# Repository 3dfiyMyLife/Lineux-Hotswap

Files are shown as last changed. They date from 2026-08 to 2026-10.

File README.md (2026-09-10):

# Lineux-Hotswap
### Diy Hotendchanger for fdm 3d printers
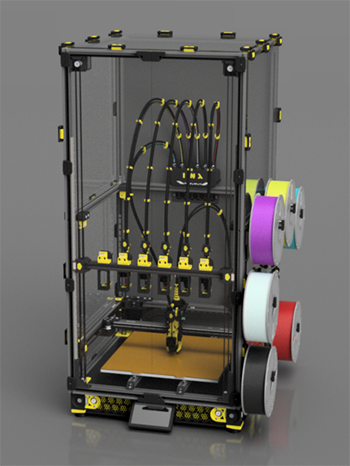
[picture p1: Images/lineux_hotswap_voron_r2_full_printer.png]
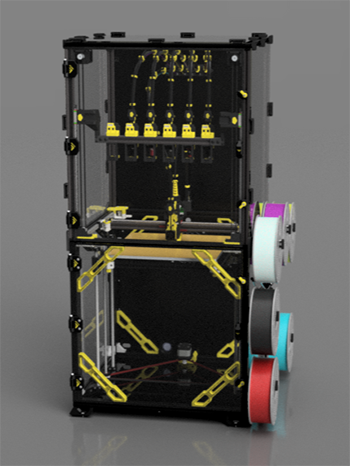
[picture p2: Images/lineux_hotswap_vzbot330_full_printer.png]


# Discord
Our Discord server can be found here:

Discord Banner 2 (https://discord.gg/Xwqbjj4VjH)
</a>

# Description
Lineux Hotswap consist of a suite of 3 parts:
1. Lineux - The hardware consisting of the Carriage, Toolhead and Dock
2. Btc - The macros handling the toolchange (Credit to @JackBeam for BTC)
3. Dockslide - Stowable dock to maximise print build

All 3 parts can be used with other systems. Example, Lineux can be used with other hotendchanger plugin. Other hotendchanger hardware can use Btc macros. Etc...

Lineux is designed as a front mounted Hotendchanger with Dockslide as our primary configuration.
If you intend to use a fixed dock configuration, pls do check or ask in discord if there are any mods or alternatives that may have already been released.

(Design, hardwares and configuration may change. Do check with us on discord)

# Is This Project for You?

This project is for makers and tinkerers who want to explore custom multi-tool 3D printing solutions.

If you’re simply looking for a plug-and-play machine, there are other great options available:

### Manufacture-ready Hotendchanger printers:
[Sovol M1D](https://www.sovol3d.com/pages/sovol-m1d-landing-page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)

### Other DIY hotendchanger projects:

[Cx Changer](https://github.com/cx330-TXY/CxChanger)

[Medusa HC](https://github.com/Irbis3D/MedusaHC)

[Yudx](https://github.com/dumplinglab/YUDX-tool-changer)

# All derivatives belong to their respective owners.<br/>
[Voron](https://github.com/vorondesign)<br/>
[Vzbot](https://github.com/VzBot3D)<br/>
[Voron CNC Carriage](https://github.com/Vitalii3D-xyz/VoronLightweightXCarriage)<br/>
[Voron Fysetc CNC Tap](https://github.com/FYSETC)<br/>

## Cost
Aside from costs at BOM, you will need these items. These are not included in the BOM
1. PSU. The power depends on the number of tools used. The hotend heater power also must be taken into account.
2. Probe. You will only need 1 probe.
3. PDB. All hotends, thermistor and hotend fans need their own ports respectively. If your mcu doesnt have enough ports for them, you need to use an additional board or an expansion board.

# BOM
BOM is [here](https://github.com/3dfiyMyLife/Lineux-Hotswap/tree/main/BOM)

# Current stage
Lineux Hotswap: Open Beta

BTC: Released

Dockslide: Released

# Instructions
Instructions/Guides are [here](https://github.com/3dfiyMyLife/Lineux-Hotswap/tree/main/Manuals)

# A huge thanks to the companies who have been supporting us
Blurolls https://blurolls3d.com/<br/>
LDO Motors https://ldomotors.com/<br/>
Polymaker https://polymaker.com/<br/>
E3D https://e3d-online.com/<br/>
RDBB rails https://a.aliexpress.com/_oB4RnLd<br/>
Fysect https://www.fysetc.com/<br/>
Trianglelab https://trianglelab.net/<br/>
Cartographer 3d https://cartographer3d.com/<br/>
JLCCNC https://jlccnc.com/<br/>
Biqu https://biqu.equipment/<br/>
Mellow 3d https://3dmellow.com/<br/>

# If you would like to support our project, you can do so on our Kofi Page
### [Ko-fi](https://ko-fi.com/lineux_toolchanger) ###

# Videos
https://github.com/user-attachments/assets/3e8e5f42-4552-4d9c-a9ab-b509341ac4d7

https://github.com/user-attachments/assets/85e045ab-b232-4179-8a6f-3297ebb0ea23

# Prints

Printed by 3dfiy My Life on vzbot330

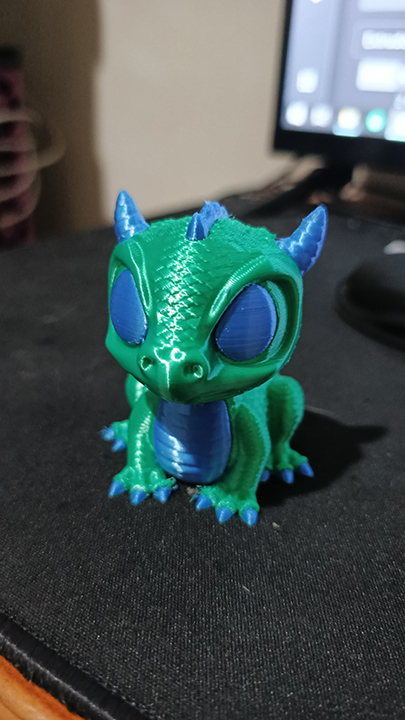
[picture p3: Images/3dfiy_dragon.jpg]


Printed by irrenhaus on voron trident r2

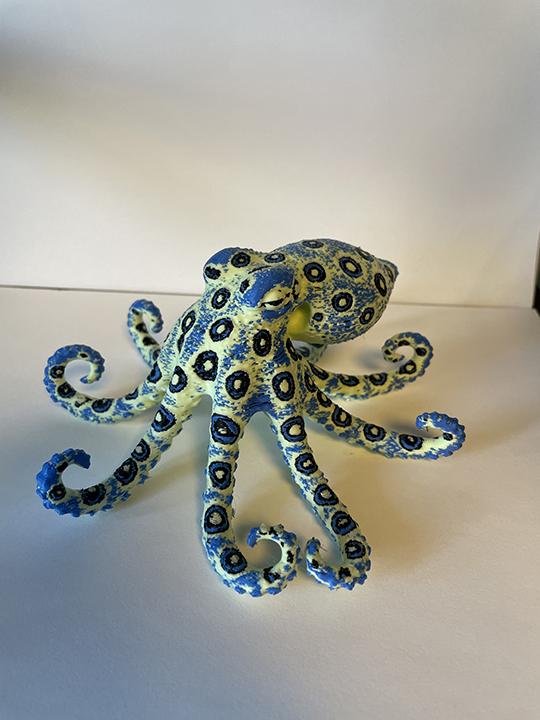
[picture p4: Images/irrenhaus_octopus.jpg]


# Printers
This project was developed on a Vzbot 330 and Voron 2.4 and Voron Trident. Other printers would need slight modifications. We could add support for other printers when there are others who had modded successfully, or when
we are able to get a hold of other printers to mod.

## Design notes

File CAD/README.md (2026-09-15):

# Overview

## Lineux Hotswap (Open Beta Release)
All cads released are based on a Voron 2.4 and Vzbot. You might need to adapt the dock and carriage to yr own printers. You can also check usermods section for any other printers cad/stl that may have been contributed by the community if they are not available here. Pls also do check in discord for any mods/contributions by the community.

Designs, mechanism and bom do get updated as we progress. Do take note. (It's a good practice to ask before committing to the build as design and hardwares may change)

# Printed Parts
Ensure the printed parts are printed without any warping to ensure proper and perfectly aligned components during installation.

It is recommended to do a test print on a small part for fitting, material shrinkage and tolerance measurement before commiting to the full printed parts.

Recommended slicer settings are as follows (Props to Voron team):
```
Layer height: 0.2mm
Extrusion width: 0.4mm
Infill pecentage: 40%
Infill type: Adaptive Cubic, grid, gyroid, honeycomb, triangle, or cubic
Wall count: 4
Solid top/bottom layers: 5
```

# Carriage
Refer to the printer carriage available or check under usermods section. Pls do check in discord as well. All carriages are designed to be front facing and utilising Dockslide.
If you are running Lineux Hotswap on a Voron 2.4 r2, you will need to use the Z chain transpose as well eg, https://www.printables.com/model/279739-voron-can-bus-z-chain-move
There are a few versions which you can search and use.

# Toolhead
Currently, we offer a few hotends compability. Do check on discord for other hotends compability which may have been made by the community.<br/>
Mellow V6 CHP<br/>
Triangle CHC pro<br/>
TZ V6 3.0<br/>
E3D Revo Voron<br/>
Phaetus Rapido<br/>

# Docks
Docks are optimized to be used with a dockslide. Do check with our discord for other types which may have been contributed by the community.

# Dockslide
Dockslide is a moving dock system to recover back any build volume loss encountered when having a fixed dock on the existing printer in which the frame wasn't extended in X or Y.

# Requirement
1. Carriage
2. Tools (Quantity depends on how many you require or may fit on yr printer. Minimum of 2 toolheads recomended)
3. Docks (1 dock per toolhead required)
4. Dockslide (You will need a fixed dock mount if you are not using dockslide)
5. Tubby / Intai (Required for tool nozzle offset calibration)

Join our [Discord](https://discord.gg/Xwqbjj4VjH) for any questions u may have. Let's go...

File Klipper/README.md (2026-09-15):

# Overview
Bikin Toolchanger (BTC) is using pure macros. It uses snippets of codes from the [Magswitch](https://github.com/jera-sea/MagSwitch-Toolchanger) project and the
[Klicky Probe](https://github.com/jlas1/Klicky-Probe).

# Nozzle Offset Calibration Tool
You can use Tubby, Intai, Nudge, Mellow Zero Precision, or any camera calibration or manual calibration. 

# Macro Status
Fully tested and working. Released.

# Files
1. btc.cfg <- Main file, required
2. btc_carriage.cfg	<- Carriage file, required
3. btc_variables.cfg <- Variables, required
4. tool_x.cfg <- Individual tool settings, required
5. btc_leds.cfg <- Leds macros, required
6. dockslide.cfg <- Required if using dockslide
7. bashed_macros.cfg <- For stress testing of hotendchanger, required after set up
8. btc_tubby.cfg <- Macros for tubby tool, required during nozzle offset calibration set up
9. btc_tubby_z.cfg <- Macros for Z calibration only if using camera for X and Y nozzle offset
10. btc_extras.cfg <- Sample macros to use in start/end print and homing override
11. btc_spoolman.cfg <- Required if using Spoolman

# Video guide

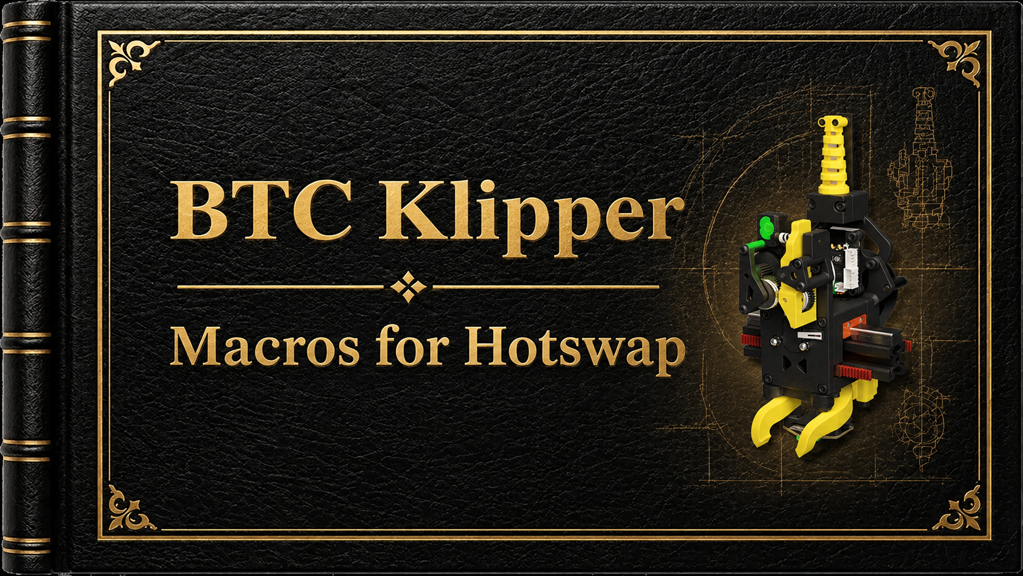
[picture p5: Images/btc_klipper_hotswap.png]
IMAGE ALT TEXT HERE (https://youtu.be/aBgHKiLgzWA?si=D5ylQy5s1Cmdv41K)


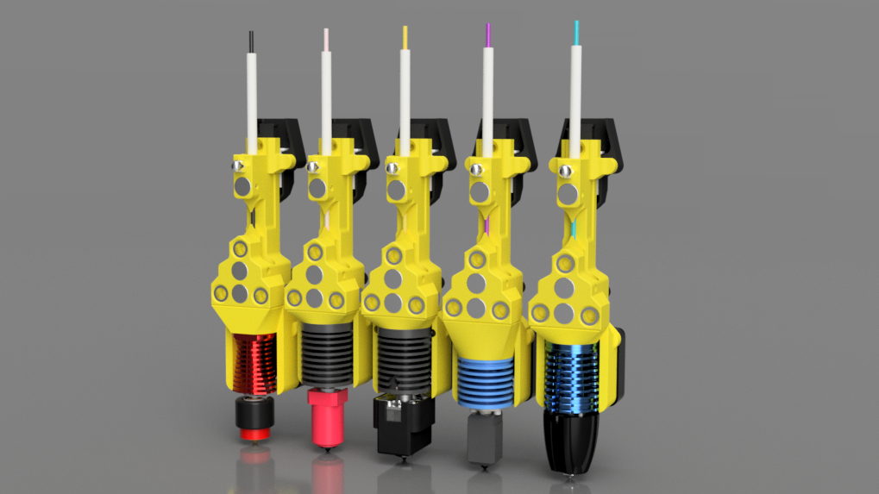
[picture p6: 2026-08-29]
Images/lineux_hotswap_tool_rear.png

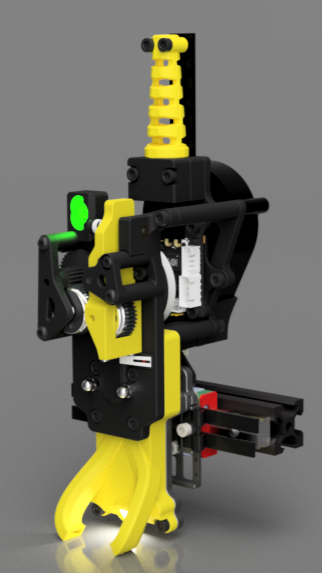
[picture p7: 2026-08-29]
Images/lineux_hotswap_cnc_tap.png

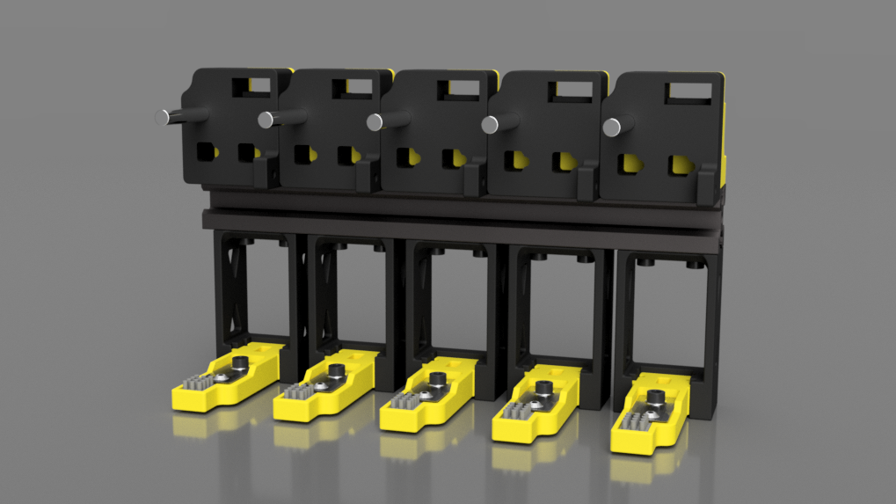
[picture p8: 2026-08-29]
Images/lineux_hotswap_docks_rear.png

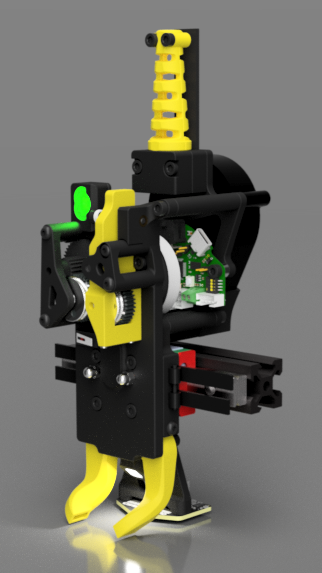
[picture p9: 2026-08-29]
Images/lineux_hotswap_voron.png

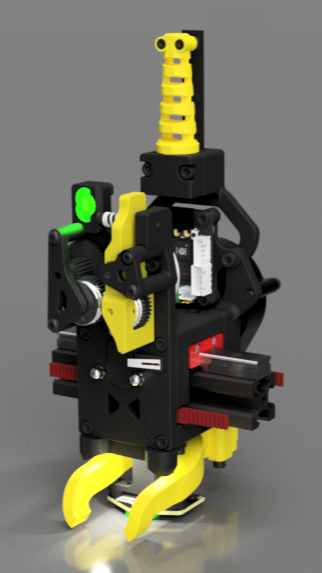
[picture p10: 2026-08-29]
Images/lineux_hotswap_vzbot.png

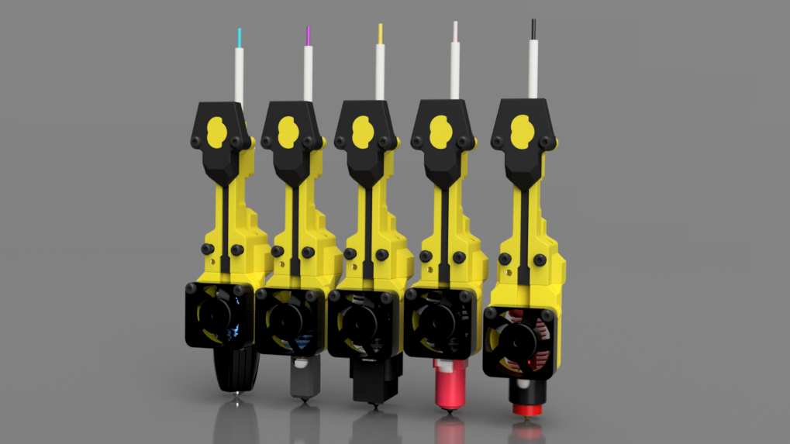
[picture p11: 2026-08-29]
Images/lineux_hotswap_tool_front.png

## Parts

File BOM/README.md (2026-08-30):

Bom are subjected to change based on testing, updates and hardwares availability.

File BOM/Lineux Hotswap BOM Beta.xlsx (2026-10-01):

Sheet: Voron
Lineux Hotswap Bill Of Material (Alpha)
Bom subjected to changes based on feedbacks and hardware availability.
Bom doesn't include probe and their respective hardwares.
Bom is for Ebb36 Toolboard. Other toolboard may need different hardwares.
Lineux Hotswap Voron Carriage | Quantity | Description | Source link | Remarks
m3x5x4 brass insert | 26
m3 hex nut | 1
m3 x 6mm bhcs | 3
m3 x 6mm shcs | 1
m3 x 8mm set screw | 3
m3 x 8mm shcs | 5
m3 x 15mm shcs | 4
m3 x 20mm shcs | 2
m3 x 25mm bhcs | 4
m3 x 30mm bhcs | 4
m3 x 30mm shcs | 1
m3 x 45mm shcs | 2
m3 cap nut din1587 | 3 |  | link (https://www.aliexpress.com/item/1005011936970787.html)
m3 x 20mm dowel pin | 2
m3 x 30mm dowel pin | 2
M5 OD7 3mm SS Bushing | 1 | 5x7x3 | link (https://www.aliexpress.com/item/1005008882769763.html)
mr63zz bearing | 2 |  |  | U need 2 extra. Not from HGX Lite kit
8 x 5mm n52 magnet | 3
microswitch | 1
ws2812 Addressable Led | 2
Nema 14 Stepper motor | 1
HGX Lite Gears | 1 | Gear Kit | link (https://www.aliexpress.com/item/1005008784674964.html) | Take note its not HGX Lite V2
Toolboard | 1 |  |  | Ebb36, H36, SHT36, Tool Lite, etc
5015 Radial Fan | 1
Lineux Hotswap Voron Dock | Quantity | Description | Source link | Remarks
m3x5x4 brass insert | 5
m3 hex nut | 1
m3 washer | 2
m3 x 6mm shcs | 3
m3 x 8mm shcs | 3
m3 x 10mm shcs | 4
m3 od5 35mm threaded dowel pin | 1 | 5x35xM3 | link (https://www.aliexpress.com/item/1005008733851932.html)
6 x 3mm n52 magnet | 1
Silicon Brush | 1 |  | link (https://www.aliexpress.com/item/1005012043811349.html) | Can be cut into 2 or 3 per piece
AA battery terminal | 1 |  | link (https://www.aliexpress.com/item/1005003438264831.html?curPageLogUid=9sgHbNrWVcU1) | Take note of dimension

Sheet: Voron Cnc Tap
Lineux Hotswap Bill Of Material (Alpha)
Bom subjected to changes based on feedbacks and hardware availability.
Bom doesn't include probe and their respective hardwares.
Bom is for Ebb36 Toolboard. Other toolboard may need different hardwares.
Lineux Hotswap Voron Carriage | Quantity | Description | Source link | Remarks
m3x5x4 brass insert | 26
m3 hex nut | 1
m3 x 6mm shcs | 6
m3 x 8mm set screw | 3
m3 x 8mm shcs | 7
m3 x 12mm shcs | 2
m3 x 20mm shcs | 2
m3 x 25mm bhcs | 4
m3 x 30mm bhcs | 4
m3 x 30mm shcs | 1
m3 x 45mm shcs | 2
m3 x 20mm dowel pin | 2
m3 x 30mm dowel pin | 2
m3 cap nut din1587 | 3 |  | link (https://www.aliexpress.com/item/1005011936970787.html)
M5 OD7 3mm SS Bushing | 1 | 5x7x3 | link (https://www.aliexpress.com/item/1005008882769763.html)
mr63zz bearing | 2 |  |  | U need 2 extra. Not from HGX Lite kit
8 x 5mm n52 magnet | 3
microswitch | 1
ws2812 Addressable Led | 2
Nema 14 Stepper motor | 1
HGX Lite Gears | 1 | Gear Kit | link (https://www.aliexpress.com/item/1005008784674964.html) | Take note its not HGX Lite V2
Toolboard | 1 |  |  | Ebb36, H36, SHT36, Tool Lite, etc
5015 Radial Fan | 1
Lineux Hotswap Voron CNC Tap Dock | Quantity | Description | Source link | Remarks
m3x5x4 brass insert | 5
m3 hex nut | 1
m3 washer | 2
m3 x 6mm shcs | 3
m3 x 8mm shcs | 3
m3 x 10mm shcs | 4
m3 od5 35mm threaded dowel pin | 1 | 5x35xM3 | link (https://www.aliexpress.com/item/1005008733851932.html)
6 x 3mm n52 magnet | 1
Silicon Brush | 1 |  | link (https://www.aliexpress.com/item/1005012043811349.html) | Can be cut into 2 or 3 per piece
AA battery terminal | 1 |  | link (https://www.aliexpress.com/item/1005003438264831.html?curPageLogUid=9sgHbNrWVcU1) | Take note of dimension

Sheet: Vzbot
Lineux Hotswap Bill Of Material (Alpha)
Bom subjected to changes based on feedbacks and hardware availability.
Bom doesn't include probe and their respective hardwares.
Bom is for Ebb36 Toolboard. Other toolboard may need different hardwares.
Lineux Hotswap Vzbot Carriage | Quantity | Description | Source link | Remarks
m3x5x4 brass insert | 36
m3 hex nut | 3
m3 x 8mm set screw | 3
m3 x 6mm shcs | 14
m3 x 8mm shcs | 7
m3 x 10mm shcs | 2
m3 x 16mm shcs | 2
m3 x 20mm shcs | 2
m3 x 25mm bhcs | 2
m3 x 30mm bhcs | 4
m3 x 30mm shcs | 1
m3 x 45mm shcs | 2
m3 cap nut din1587 | 3 |  | link (https://www.aliexpress.com/item/1005011936970787.html)
M5 OD7 3mm SS Bushing | 1 | 5x7x3 | link (https://www.aliexpress.com/item/1005008882769763.html)
m3 x 20mm dowel pin | 4
m3 x 30mm dowel pin | 2
mr63zz bearing | 2 |  |  | U need 2 extra. Not from HGX Lite kit
8 x 5mm n52 magnet | 3
microswitch | 1
ws2812 Addressable Led | 3
Nema 14 Stepper motor | 1
HGX Gears | 1 | Gear Kit | link (https://www.aliexpress.com/item/1005008784674964.html) | Take note its not HGX Lite V2
Toolboard | 1 |  |  | Ebb36, H36, SHT36 etc
5015 Radial Fan | 1
Lineux Hotswap Vzbot Dock | Quantity | Description | Source link | Remarks
m3x5x4 brass insert | 5
m3 hex nut | 1
m3 washer | 2
m3 x 6mm shcs | 3
m3 x 8mm shcs | 5
m3 x 10mm shcs | 2
m3 od5 35mm threaded dowel pin | 1 | 5x35xM3 | link (https://www.aliexpress.com/item/1005008733851932.html)
6 x 3mm n52 magnet | 1
Silicon Brush | 1 |  | link (https://www.aliexpress.com/item/1005012043811349.html) | Can be cut into 2 or 3 per piece
AA battery terminal | 1 |  | link (https://www.aliexpress.com/item/1005003438264831.html?curPageLogUid=9sgHbNrWVcU1) | Take note of dimension

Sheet: Tool
Lineux Hotswap Bill Of Material (Alpha)
Bom subjected to changes based on feedbacks and hardware availability.
Bom is based on V6 ChP. Other hotends may require different hardwares.
Lineux Hotswap Toolhead | Quantity | Description | Source link | Remarks
m2.5 x 6mm shcs | 4 | For V6 CHP |  | Heatsink Mounting Screw
m3x5x4 brass insert | 9
m3 x 6mm fhcs | 1
m3 x 8mm set screw | 1
m3 x 8mm shcs | 2
m3 x 10mm bhcs | 2
m3 x 12mm bhcs | 2
m3 x 15mm bhcs | 2 |  |  | m3 x 16mm also possible
m3 cap nut din1587 | 1 |  | link (https://www.aliexpress.com/item/1005011936970787.html)
M5 OD7 3mm SS Bushing | 3 | 5x7x3 | link (https://www.aliexpress.com/item/1005008882769763.html)
6 x 3mm n52 magnet | 1
8 x 5mm n52 magnet | 3
3010 Axial Fan | 1 | between 9-12mm width |  | Length depends on printer size
Industrial ziptie (between 9-10mm width recommended) | 1 | For umbilical |  | Length depends on yr build.
jst xh 4pin female housing | 1 | Can use Molex 2x3p as an alternative | link (https://www.aliexpress.com/item/1005007287524489.html?curPageLogUid=jkflrg33MYGo) | Take note of the type
jst xh 4pin male | 1
molex 1x2pin male | 1 |  | link (https://www.aliexpress.com/item/1005006994933599.html?curPageLogUid=Kcjoww0hTpt0) | Take note of the clip position
molex 1x2pin female | 1 |  | link (https://www.aliexpress.com/item/1005006994933599.html?curPageLogUid=Kcjoww0hTpt0)
Ptfe Tube ID2 OD4 | 1 | 40mm |  | Length depends on hotends.
Hotend |  |  |  | Depends on your choice

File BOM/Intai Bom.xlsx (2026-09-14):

Intai- Camera Based Nozzle Offset Calibration Tool
Bom subjected to changes based on feedbacks and hardware availability.
All links are non affiliated. Links are provided as a reference to check the hardware dimensions, visual, etc.
Fixed Base (Magnet Version) | Quantity | Description | Link
m3x5x4 brass insert | 4
m3 x 6mm bhcs | 1
m3 x 8mm shcs | 2
m3 x 12mm bhcs | 3
m3 x 15mm bhcs | 1
m3 x OD4 16mm threaded dowel pin | 1 |  | link (https://www.aliexpress.com/item/1005005150593994.html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)
6 x 3mm magnet | 2 | n35 or lower
OV9726 Camera module | 1 |  | link (https://www.aliexpress.com/item/1005004029465825.html)
5v 3mm white led diode | 6 |  | link (https://www.aliexpress.com/item/1005004771200688.html)
jst xh2.54 connector 2pin female | 1 | Refer to cad if unsure which is female
Ring Terminal (RNB 1.25-3) | 1 | optional
Floating Base (Magnet Version) | Quantity | Description
m3x5x4 brass insert | 4
m3 x 6mm bhcs | 1
m3 x 12mm bhcs | 3
m3 x 15mm bhcs | 1
m3 x OD4 16mm threaded dowel pin | 1 |  | link (https://www.aliexpress.com/item/1005005150593994.html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)
6 x 3mm magnet | 2 | n35 or lower
6 x 3mm magnet | 4 | n52
OV9726 Camera module | 1 |  | link (https://www.aliexpress.com/item/1005004029465825.html)
5v 3mm white led diode | 6 |  | link (https://www.aliexpress.com/item/1005004771200688.html)
jst xh2.54 connector 2pin female | 1 | Refer to cad if unsure which is female
Ring Terminal (RNB 1.25-3) | 1 | optional
Floating Base (Switch Version) | Quantity | Description
m3x5x4 brass insert | 4
m3 x 12mm bhcs | 2
m3 x 15mm bhcs | 2
m3 x 10mm dowel pin | 1
m3 x OD4 16mm threaded dowel pin | 1 |  | link (https://www.aliexpress.com/item/1005005150593994.html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)
6 x 3mm magnet | 4 | n52
microswitch | 1
OV9726 Camera module | 1 |  | link (https://www.aliexpress.com/item/1005004029465825.html)
5v 3mm white led diode | 6 |  | link (https://www.aliexpress.com/item/1005004771200688.html)
jst xh2.54 connector 2pin female | 1 | Refer to cad if unsure which is female

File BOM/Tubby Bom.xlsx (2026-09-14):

Tubby - Nozzle Offset Calibration Tool
6x3mm Floating Base | Quantity | Description
m3 x 6mm shcs | 1
m3 x 16mm bhcs | 2
m3 brass insert | 2
m3 x 8mm dowel | 1 | Solder a wire to one end of the dowel
12mm steel ball bearing | 1
6 x 3mm n35 magnet | 6 | n35 or lower
JST XH 2.1 Female | 1
8x5mm Floating Base | Quantity | Description
m3 x 6mm shcs | 1
m3 x 16mm bhcs | 2
m3 brass insert | 2
m3 x 8mm dowel | 1 | Solder a wire to one end of the dowel
12mm steel ball bearing | 1
6 x 3mm n35 magnet | 3 | n35 or lower
8 x 5mm n35 magnet | 3 | n35 or lower
JST XH 2.1 Female | 1
10x5mm Floating Base | Quantity | Description
m3 x 6mm shcs | 1
m3 x 16mm bhcs | 2
m3 brass insert | 2
m3 x 8mm dowel | 1 | Solder a wire to one end of the dowel
12mm steel ball bearing | 1
6 x 3mm n35 magnet | 3 | n35 or lower
10 x 5mm n35 magnet | 3 | n35 or lower
JST XH 2.1 Female | 1
Fixed Base | Quantity | Description
m3 x 15mm shcs | 1
m3 x 16mm bhcs | 2
m3 x 25mm shcs | 2
m3 brass insert | 2
m3 x 8mm dowel | 1 | Solder a wire to one end of the dowel
12mm steel ball bearing | 1
6 x 3mm n35 magnet | 3 | n35 or lower
JST XH 2.1 Female | 1

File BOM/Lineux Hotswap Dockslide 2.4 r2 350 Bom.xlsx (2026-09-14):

Lineux Hotswap Dockslide 2.4 r2 350 Bill Of Material
Bom subjected to changes based on feedbacks and hardware availability.
Bom does not include panel clip/latch, door hinge and their respective hardwares.
Item | Quantity | Description | Source link | Remarks
2020 T-slot extrusion 1000mm | 2 | Tophat height is 470mm |  | Use the calculator below to get the required front extrusion length and rail length. Tophat height may be affected by bed size and umbilical length.
2020 T-slot extrusion 490mm | 2
2020 T-slot extrusion 470mm | 4
2020 T-slot extrusion 400mm | 1
MGN9C + Rail 650mm | 2
GT2 20T Pulley 9mm Belt ID5 | 2 |  |  | 10mm belt is fine too.
GT2 20T Toothed Idler 9mm Belt ID5 | 2 |  |  | 10mm belt idler is fine too.
Gates Belt 9mm 1.9metres | 2
Nema 17 Stepper | 2 | LDO-42STH40-1684AC |  | Recommended Motor
Micro switch | 2
m3 heat insert | 2 |  |  | m3xod5x4
m3 x 8mm bhcs | 8
m3 x 8mm shcs | 34
m3 x 20mm bhcs | 2
m3 x 25mm shcs | 8
m3 x 40mm shcs | 2
m5 x 8mm bhcs | 2
m5 x 10mm bhcs | 18
m5 x 20mm bhcs | 2
2020 hidden corner bracket | 16 |  |  | If not using blind joints
2020 parallel joint | 4
2020 straight line joint | 2
Panels
Top 504 x 484mm | 1 | Transparent |  | Size is based on Voron 2.4 r2 350
Sides 504 x 344mm | 2 | Transparent
Back 484 x 344mm | 1 | Opaque
Door 241.5 x 973.5mm | 2 | Transparent
Dockslide Required Length Calculator
Description |  | Enter Length | Required Length | Remarks
Step 1. To calculate the required dockslide vertical extrusion length, enter yr printer front vertical extrusion length |  | 530 | 1000 | Length may be affected by bed size and umbilical length.
Step 2. To calculate the required rail length, enter yr dockslide required vertical extrusion length |  | 1000 | 650
Step 3. To calculate dock extrusion bar length, enter yr printer horizontal extrusion length |  | 470 | 400
Step 4. To calculate the maximum number of tools you can install, enter dock extrusion bar length |  | 400 | 10 | Round down number

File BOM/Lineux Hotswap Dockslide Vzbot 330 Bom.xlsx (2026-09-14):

Dockslide Vzbot 330 Bill Of Material
Bom subjected to changes based on feedbacks and hardware availability.
Bom does not include panel clip/latch, door hinge and their respective hardwares.
Item | Quantity | Description | Source link | Remarks
2020 T-slot extrusion 550mm | 4 | Tophat height is 565mm
2020 T-slot extrusion 530mm | 2
2020 T-slot extrusion 460mm | 2
2020 T-slot extrusion 360mm | 1
MGN9H + Rail 350mm | 2
Hardware | Quantity | Description | Source link | Remarks
GT2 20T Pulley 9mm Belt ID5 | 2 |  |  | 10mm belt is fine too.
GT2 20T Toothed Idler 9mm Belt ID5 | 2 |  |  | 10mm belt idler is fine too.
Gates Belt 9mm 1.1 meter | 2
Nema 17 Stepper | 2 | LDO-42STH40-1684AC |  | Recommended Motor
Micro switch | 2
m3 heat insert | 2 |  |  | m3xod5x4
m3 x 8mm bhcs | 8
m3 x 8mm shcs | 16
m3 x 20mm bhcs | 2
m3 x 25mm shcs | 8
m3 x 40mm shcs | 2
m5 x 8mm bhcs | 8 |  |  | For corner bracket
m5 x 10mm bhcs | 34
m5 x 20mm bhcs | 2
m5 t-nut | 8 |  |  | For corner bracket
2020 corner bracket | 4 |  |  | Optional For stiffness
2020 hidden corner bracket | 4 |  |  | Optional For stiffness
Panels
Top 503.5 x 473.5mm | 1 | Transparent
Sides 556.5 x 470.5mm | 2 | Transparent
Back 555.0 x 504.5mm | 1 | Opaque
Door 564.5 x 516mm | 1 | Transparent

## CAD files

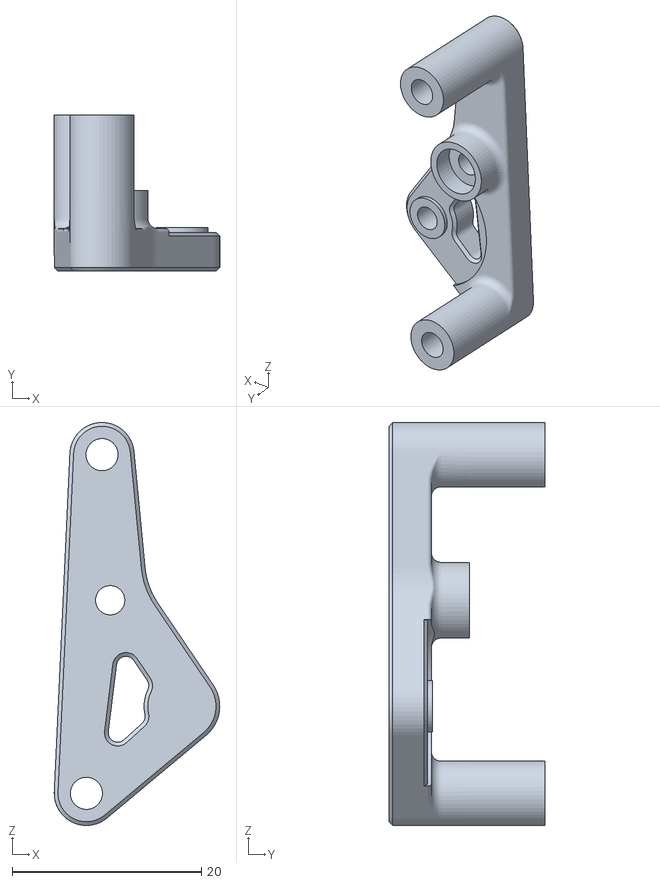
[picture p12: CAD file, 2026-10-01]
STLs/Carriage/Voron Cnc Tap/Carriage/gear_plate.stl
17.5 x 16.5 x 42.6

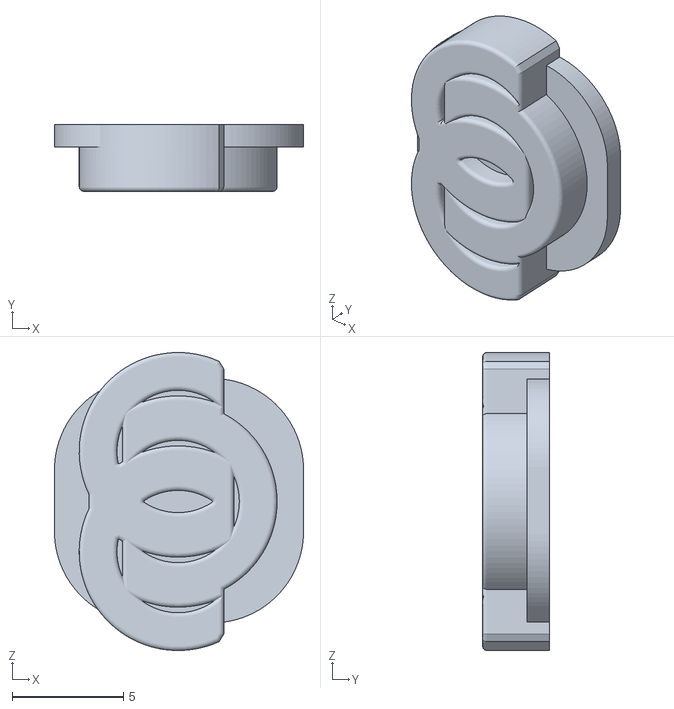
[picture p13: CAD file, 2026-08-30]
STLs/Carriage/Voron Cnc Tap/Led/diffuser.stl
11.2 x 3.00 x 13.4

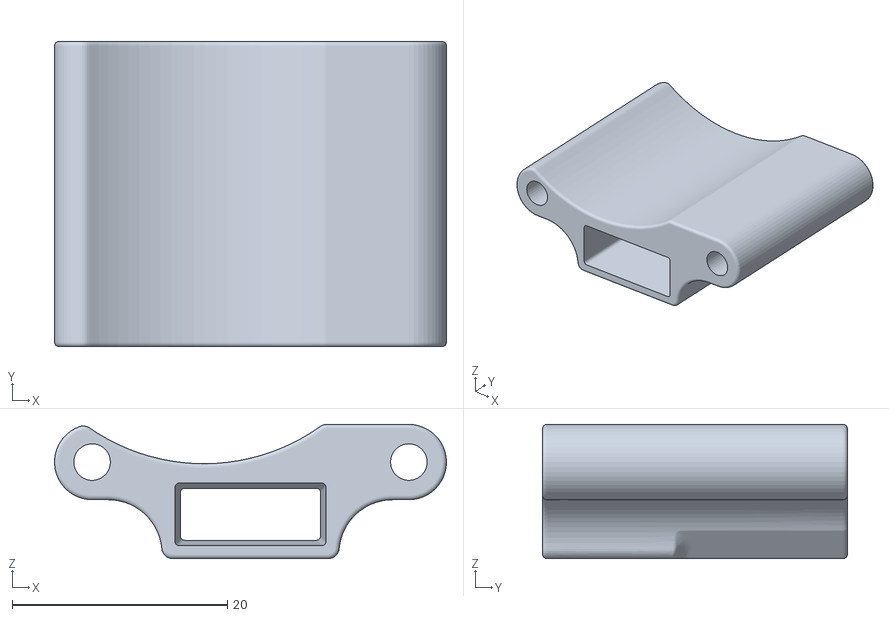
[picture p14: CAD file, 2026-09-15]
STLs/Carriage/Voron Cnc Tap/Part Cooling/duct_extension.stl
36.4 x 28.4 x 12.5

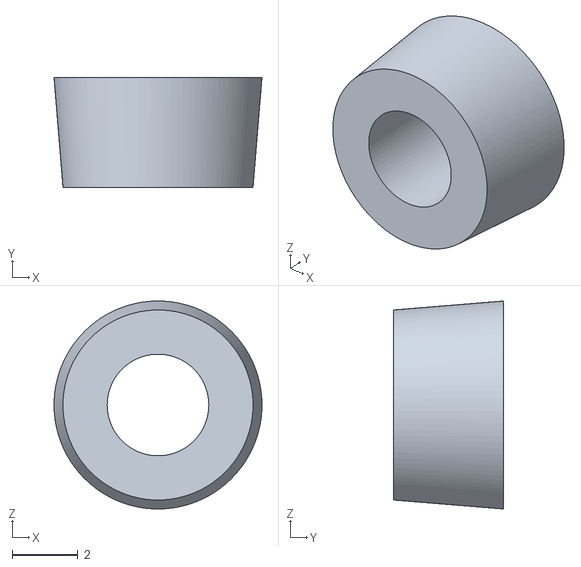
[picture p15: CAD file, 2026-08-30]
STLs/Carriage/Voron Cnc Tap/Toolboard/ebb36_spacer_x2.stl
6.35 x 3.36 x 6.35

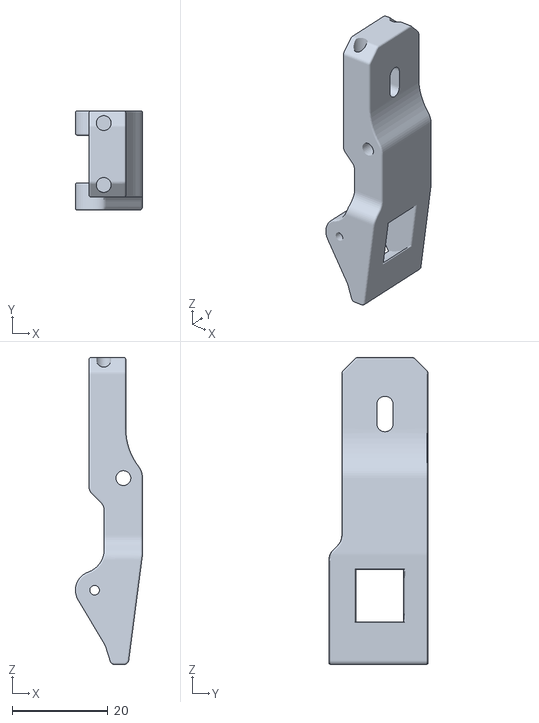
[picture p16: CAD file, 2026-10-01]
STLs/Carriage/Voron/Carriage/[a]_latch.stl
14.0 x 20.7 x 64.0

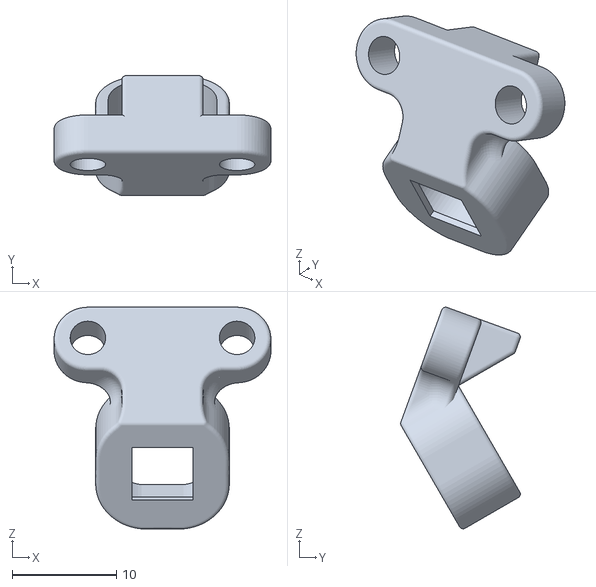
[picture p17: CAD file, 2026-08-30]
STLs/Carriage/Voron/Led/led_mount.stl
20.8 x 11.5 x 21.2

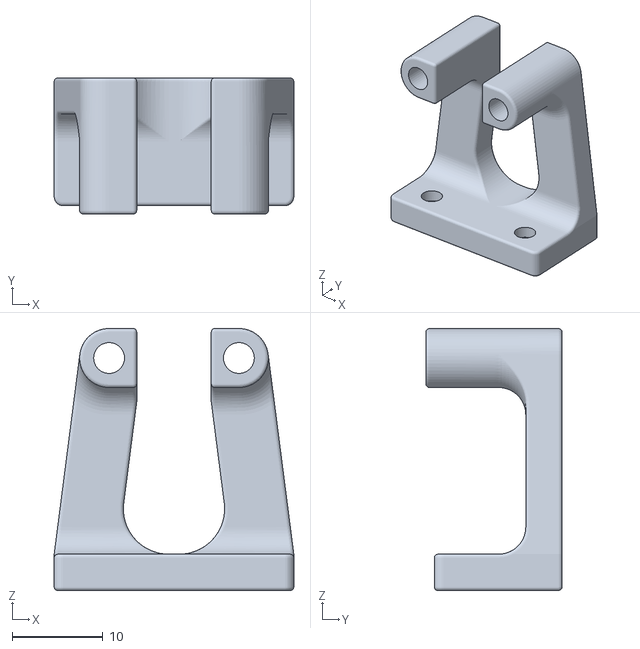
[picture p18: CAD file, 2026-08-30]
STLs/Carriage/Voron/Probe/klicky_mount.stl
26.4 x 15.0 x 28.9

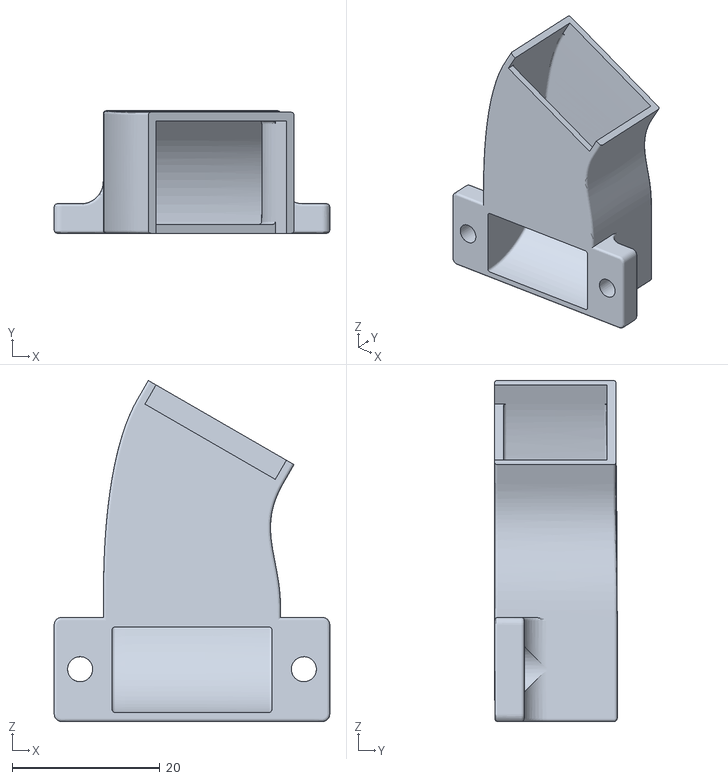
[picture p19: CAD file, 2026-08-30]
STLs/Carriage/Vzbot330/Part Cooling/[a]_5015_adapter.stl
37.3 x 16.6 x 46.2

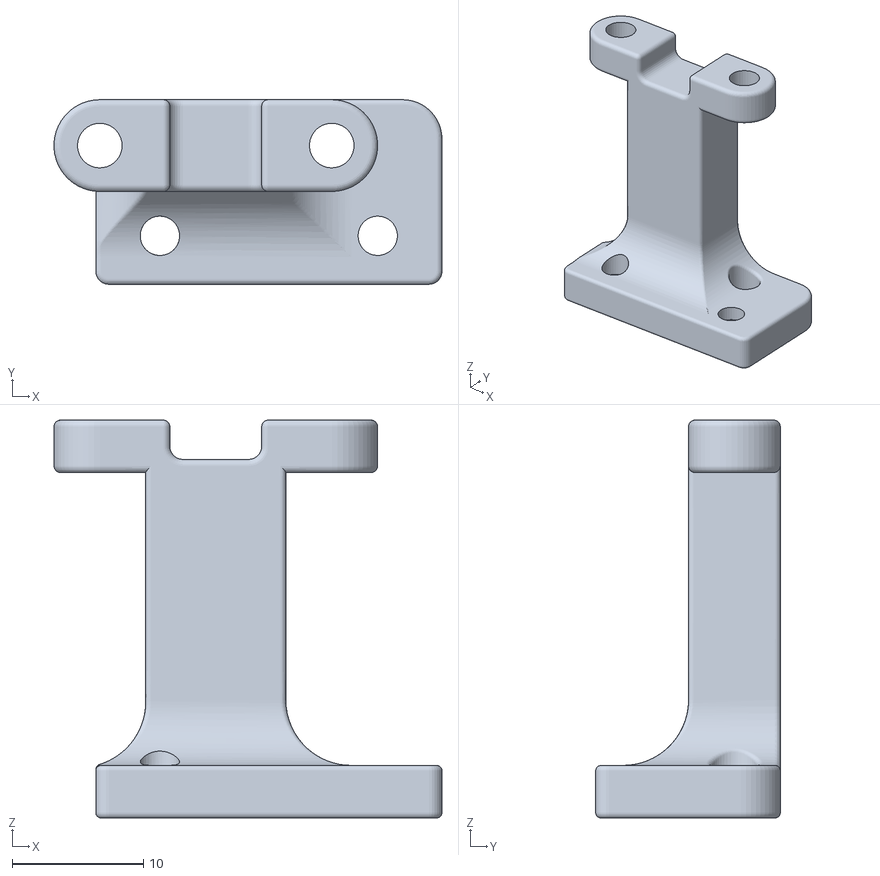
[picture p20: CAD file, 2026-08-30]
STLs/Carriage/Vzbot330/Probe/klicky_mount.stl
29.6 x 14.1 x 30.3

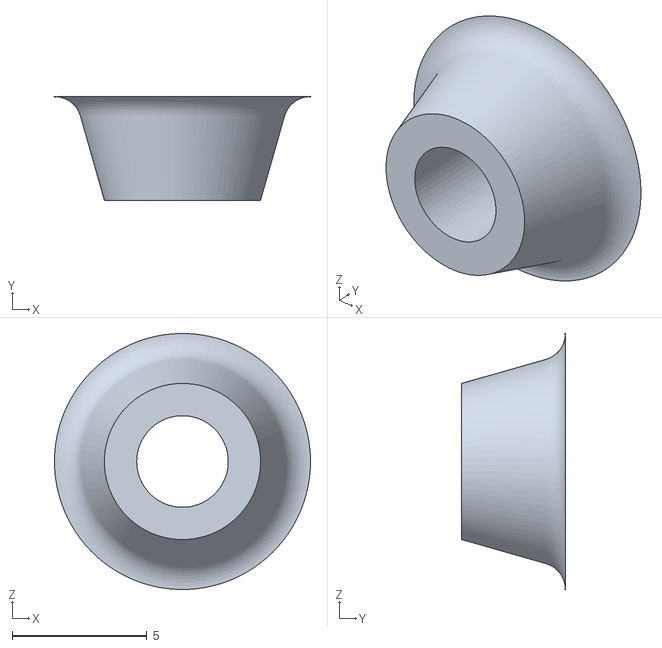
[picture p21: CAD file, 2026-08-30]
STLs/Carriage/Vzbot330/Toolboard/ebb36_spacer_x2.stl
9.51 x 3.86 x 9.51

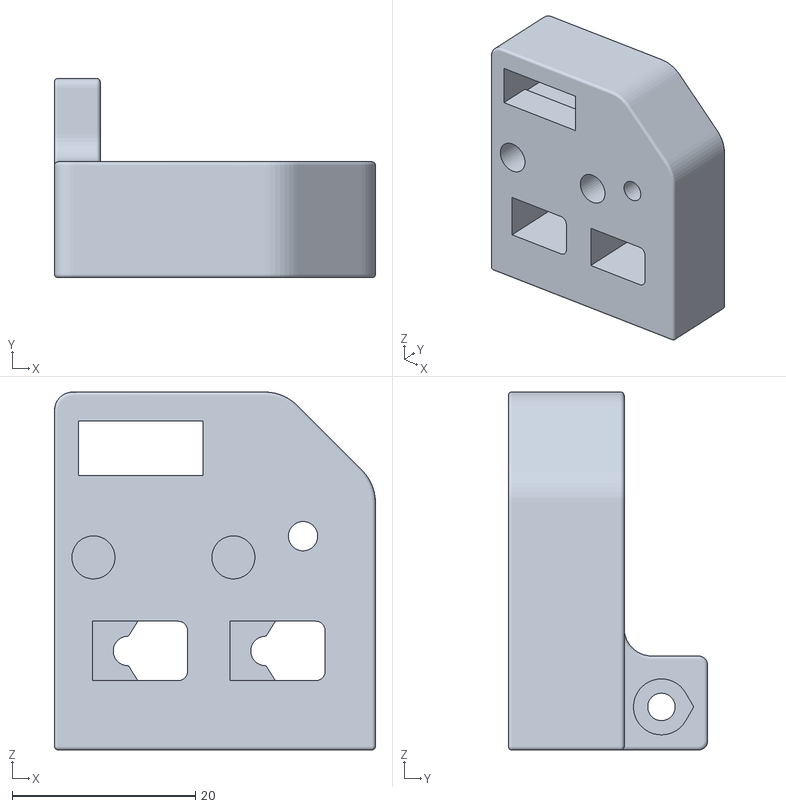
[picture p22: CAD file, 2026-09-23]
STLs/Dock/Voron CNC Tap/dock.stl
35.0 x 21.8 x 39.0

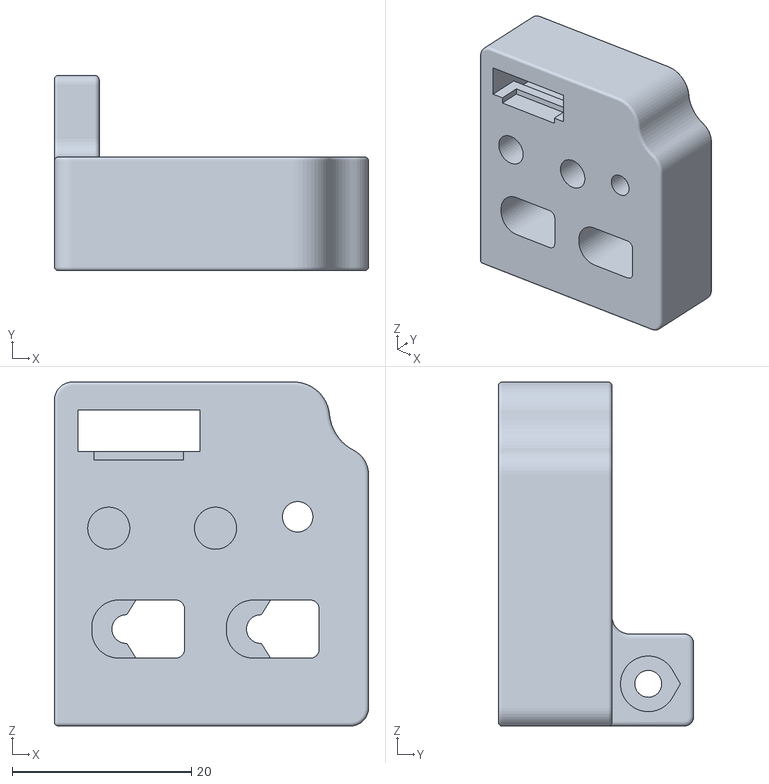
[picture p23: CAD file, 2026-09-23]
STLs/Dock/Vzbot/dock.stl
35.0 x 21.8 x 38.3

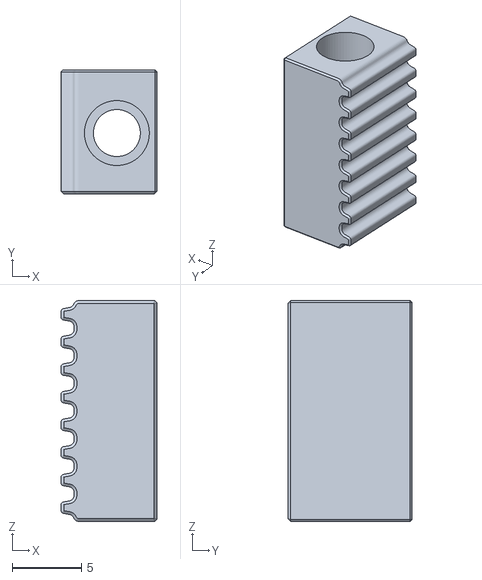
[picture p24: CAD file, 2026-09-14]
STLs/Dockslide/Voron 2.4 r2 350/[a]_belt_tensioner_x2.stl
6.95 x 9.00 x 16.0

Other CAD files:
STLs/Carriage/Voron/Part Cooling/duct_extension.stl
STLs/Carriage/Vzbot330/Carriage/[a]_latch.stl
STLs/Carriage/Vzbot330/Led/diffuser.stl
STLs/Dock/Voron/dock.stl
STLs/Carriage/Voron Cnc Tap/Carriage/[a]_latch.stl
STLs/Carriage/Voron Cnc Tap/Carriage/carriage.stl
STLs/Carriage/Voron Cnc Tap/Carriage/latch_plate.stl
STLs/Carriage/Voron Cnc Tap/Led/led_cover.stl
STLs/Carriage/Voron Cnc Tap/Part Cooling/5015_adapter.stl
STLs/Carriage/Voron Cnc Tap/Part Cooling/5015_standoff_x2.stl
STLs/Carriage/Voron Cnc Tap/Part Cooling/[a]_carriage_duct.stl
STLs/Carriage/Voron Cnc Tap/Part Cooling/screw_spacer.stl
STLs/Carriage/Voron Cnc Tap/Toolboard/mellow_tool_lite_mount.stl
STLs/Carriage/Voron Cnc Tap/Toolboard/pug_collar_front.stl
STLs/Carriage/Voron Cnc Tap/Toolboard/pug_collar_rear.stl
STLs/Carriage/Voron/Carriage/carriage.stl
STLs/Carriage/Voron/Carriage/carriage_base.stl
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

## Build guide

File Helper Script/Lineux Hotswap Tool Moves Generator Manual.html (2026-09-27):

# Lineux Hotswap Tool Moves Generator (Manual Version)

Enter X and Y positions to generate your tool.cfg block.

Dock Location X (current_x)

Dock Location Y (current_y)

Generate Front Tool Moves Generate Rear Tool Moves

Generated Configuration Block Copy Code

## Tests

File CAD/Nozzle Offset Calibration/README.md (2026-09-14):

Nozzle Offset Calibration
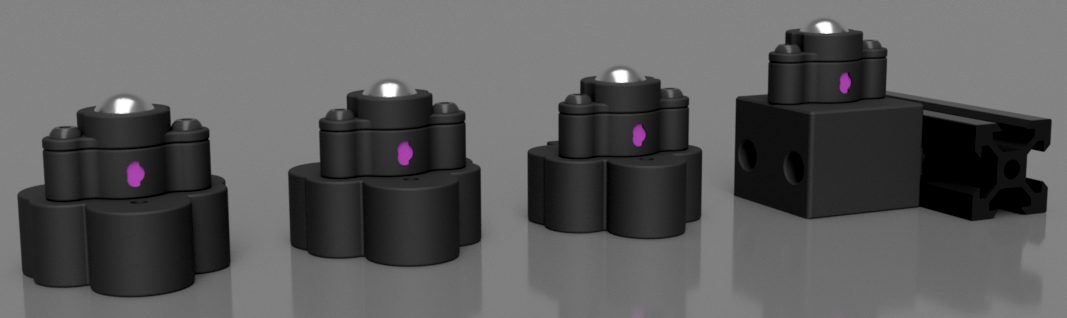
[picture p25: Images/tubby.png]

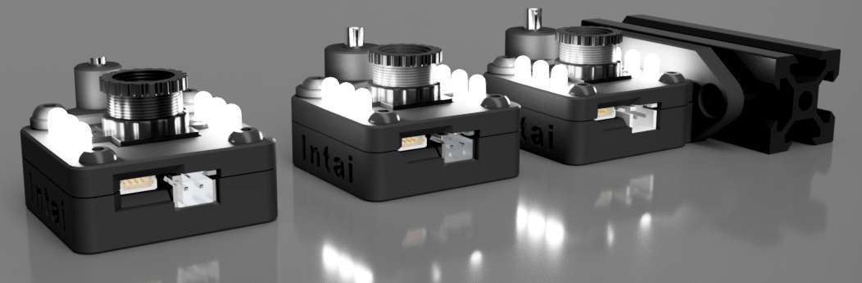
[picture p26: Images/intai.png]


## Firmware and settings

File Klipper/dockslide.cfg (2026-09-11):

[gcode_macro _DOCKSLIDE_VARIABLES]
variable_travel_speed: 400
variable_deploy_height: 3.5  #for fixed dock / fixed gantry printer
variable_deploy_offset: 0  #for flying gantry printer
variable_park_height: 200
variable_safe_y: 100
variable_safe_z: 17
variable_front_dock: True
variable_travel_resolution: 1
######################################
# Below variables are used during runtime. DO NOT edit!!
variable_dockslide_status: 0 # 0: unknown, 1: park, 2: deploy: 3:standby
variable_dockslide_homed: False
variable_doing_homing: False
variable_travel_acc: 5000
variable_home_init_speed: 50
variable_home_init_move: 5
variable_cur_pos_right: 5
variable_cur_pos_left:  5
variable_count: 0
variable_count1: 0
variable_motornum: 2
variable_flying_gantry: False
gcode:

[multi_pin ds_brake]
pins: !PD4

[tmc2209 manual_stepper motor_right]
uart_pin: PE1
run_current: 1.0
hold_current: 0.5
interpolate: False
stealthchop_threshold: 999999

[manual_stepper motor_right]
step_pin: PE2
dir_pin: PE3
enable_pin: multi_pin:ds_brake
full_steps_per_rotation: 200
rotation_distance: 40
microsteps: 16

[gcode_button dockslide_endstop_right]
pin: ^!PG10
press_gcode:
release_gcode:

#################################################
# Second motor for vertical Dockslide
# Horizontal Dockslide does not require second motor since both motors combined into a single stepper driver
# For horizontal Dockslide, eg in sling, Comment out the following
[tmc2209 manual_stepper motor_left]
uart_pin: PD3
run_current: 1.0
hold_current: 0.5
interpolate: False
stealthchop_threshold: 999999

[manual_stepper motor_left]
step_pin: PE6
dir_pin: !PA14
enable_pin: !PE0
full_steps_per_rotation: 200
rotation_distance: 40
microsteps: 16

[gcode_button dockslide_endstop_left]
pin: ^!PG11
press_gcode:
release_gcode:
# Second motor ends
#####################################################

[gcode_macro DOCKSLIDE_CHECK_STATUS]
gcode:
  {% set dockslide_status = printer["gcode_macro _DOCKSLIDE_VARIABLES"].dockslide_status %}
  {% if dockslide_status == 0 %}
    {% set statustxt = "Unknown" %}
  {% elif dockslide_status == 1 %}
    {% set statustxt = "Park" %}
  {% elif dockslide_status == 2 %}
    {% set statustxt = "Deploy" %}
  {% else %}
    {% set statustxt = "Standby" %}
  {% endif %}
  { action_respond_info("Dockslide: " + statustxt) }

[gcode_macro DOCKSLIDE_MANUAL_MOVE]
gcode:
  {% set pos = params.POS|int %}
  {% set travel_speed = params.SPEED|default(100)|int %}
  {% set travel_acc = params.ACC|default(1000)|int %}
  _CHECK_SINGLE_MOTOR
  {% set motornum = printer["gcode_macro _DOCKSLIDE_VARIABLES"].motornum %}
  {% if motornum == 2 %}
    MANUAL_STEPPER STEPPER=motor_right MOVE={pos} SPEED={travel_speed} SYNC=0 ACCEL={travel_acc}
    MANUAL_STEPPER STEPPER=motor_left MOVE={pos} SPEED={travel_speed} SYNC=1 ACCEL={travel_acc}
  {% else %}
    MANUAL_STEPPER STEPPER=motor_right MOVE={pos} SPEED={travel_speed} SYNC=1 ACCEL={travel_acc}
  {% endif %}

[gcode_macro DOCKSLIDE_PARK]
gcode:
  {% set dockvar = printer["gcode_macro _DOCKSLIDE_VARIABLES"] %}
  {% set travel_speed = dockvar.travel_speed %}
  {% set move_pos = dockvar.park_height %}
  {% set travel_acc = dockvar.travel_acc %}
  {% set motornum = dockvar.motornum %}
  {% if dockvar.flying_gantry %}
    {% set move_pos = move_pos + printer.toolhead.position.z %}
  {% endif %}
  {% if tool_approachlocation_z == 0 %}
    {% if motornum == 2 %}
      MANUAL_STEPPER STEPPER=motor_right MOVE={move_pos} SPEED={travel_speed} SYNC=0 ACCEL={travel_acc} # STOP_ON_ENDSTOP=1
      MANUAL_STEPPER STEPPER=motor_left MOVE={move_pos} SPEED={travel_speed} SYNC=1 ACCEL={travel_acc} # STOP_ON_ENDSTOP=1
    {% else %}
      MANUAL_STEPPER STEPPER=motor_right MOVE={move_pos} SPEED={travel_speed} SYNC=1 ACCEL={travel_acc} # STOP_ON_ENDSTOP=1
    {% endif %}
  {% else %}
    {% if motornum == 2 %}
      MANUAL_STEPPER STEPPER=motor_right MOVE={move_pos} SPEED={travel_speed} SYNC=0 ACCEL={travel_acc} # STOP_ON_ENDSTOP=1
      MANUAL_STEPPER STEPPER=motor_left MOVE={move_pos} SPEED={travel_speed} SYNC=1 ACCEL={travel_acc} # STOP_ON_ENDSTOP=1
    {% else %}
      MANUAL_STEPPER STEPPER=motor_right MOVE={move_pos} SPEED={travel_speed} SYNC=1 ACCEL={travel_acc} # STOP_ON_ENDSTOP=1
    {% endif %}
  {% endif %}
  SET_GCODE_VARIABLE MACRO=_DOCKSLIDE_VARIABLES VARIABLE=dockslide_status VALUE=1

[gcode_macro DOCKSLIDE_DEPLOY]
gcode:
  {% set position_y = printer.toolhead.position.y %}
  {% set position_z = printer.toolhead.position.z %}
  {% set dockvar = printer["gcode_macro _DOCKSLIDE_VARIABLES"] %}
  {% set travel_speed = dockvar.travel_speed %}
  {% set travel_acc = dockvar.travel_acc %}
  {% set move_pos = dockvar.deploy_height %}
  {% set deploy_offset = dockvar.deploy_offset %}
  {% set safe_y = dockvar.safe_y %}
  {% set safe_z = dockvar.safe_z %}
  {% set front_dock = dockvar.front_dock %}
  {% set motornum = dockvar.motornum %}
  {% if dockvar.flying_gantry %}
    {% set move_pos = printer.toolhead.position.z - deploy_offset %}
  {% endif %}
  {% set tool_approachlocation_z = printer["gcode_macro _BTC_VARIABLES"].tool_approachlocation_z %}
  {% if (position_y < safe_y and front_dock) or (position_y > safe_y and not front_dock) %}
    { action_respond_info("Dockslide: Unable to deploy Dockslide, cannot clear safe_y!") }
  {% else %}
  {% set new_position_z = printer.toolhead.position.z %}
    {% if position_z < safe_z %}
      G0 Z{safe_z}
      {% set new_position_z = safe_z %}
    {% endif %}
    {% if dockvar.flying_gantry %}
      {% set move_pos = new_position_z - deploy_offset %}
    {% endif %}
    {% if tool_approachlocation_z == 0 %}
      {% if motornum == 2 %}
        MANUAL_STEPPER STEPPER=motor_right MOVE={move_pos} SPEED={travel_speed} SYNC=0 ACCEL={travel_acc}
        MANUAL_STEPPER STEPPER=motor_left MOVE={move_pos} SPEED={travel_speed} SYNC=1 ACCEL={travel_acc}
      {% else %}
        MANUAL_STEPPER STEPPER=motor_right MOVE={move_pos} SPEED={travel_speed} SYNC=1 ACCEL={travel_acc}
      {% endif %}
    {% else %}
      {% if motornum == 2 %}
        MANUAL_STEPPER STEPPER=motor_right MOVE={move_pos} SPEED={travel_speed} SYNC=0 ACCEL={travel_acc}
        MANUAL_STEPPER STEPPER=motor_left MOVE={move_pos} SPEED={travel_speed} SYNC=1 ACCEL={travel_acc}
      {% else %}
        MANUAL_STEPPER STEPPER=motor_right MOVE={move_pos} SPEED={travel_speed} SYNC=1 ACCEL={travel_acc}
      {% endif %}
    {% endif %}
    SET_GCODE_VARIABLE MACRO=_DOCKSLIDE_VARIABLES VARIABLE=dockslide_status VALUE=2
  {% endif %}

[gcode_macro _DOCKSLIDE_WIPE]
gcode:
  {% set direction = params.DIRECTION|default(1)|int %}
  {% set travel_speed = params.FEEDRATE|default(600)|int %}
  {% set dockvar = printer["gcode_macro _DOCKSLIDE_VARIABLES"] %}
  {% set travel_acc = dockvar.travel_acc %}
  {% if direction > 0 %} # Dock at rear
    {% set move_pos1 = dockvar.deploy_height - 15 %}
    {% set move_pos2 = dockvar.deploy_height - 2 %}
  {% else %}
    {% set move_pos1 = dockvar.deploy_height + 15 %}
    {% set move_pos2 = dockvar.deploy_height + 2 %}
  {% endif %}
  {% set motornum = dockvar.motornum %}
  {% if motornum == 2 %}
    MANUAL_STEPPER STEPPER=motor_right MOVE={move_pos1} SPEED={travel_speed} SYNC=0 ACCEL={travel_acc}
    MANUAL_STEPPER STEPPER=motor_left MOVE={move_pos1} SPEED={travel_speed} SYNC=1 ACCEL={travel_acc}
    MANUAL_STEPPER STEPPER=motor_right MOVE={move_pos2} SPEED={travel_speed} SYNC=0 ACCEL={travel_acc}
    MANUAL_STEPPER STEPPER=motor_left MOVE={move_pos2} SPEED={travel_speed} SYNC=1 ACCEL={travel_acc}
    MANUAL_STEPPER STEPPER=motor_right MOVE={move_pos1} SPEED={travel_speed} SYNC=0 ACCEL={travel_acc}
    MANUAL_STEPPER STEPPER=motor_left MOVE={move_pos1} SPEED={travel_speed} SYNC=1 ACCEL={travel_acc}
    MANUAL_STEPPER STEPPER=motor_right MOVE={move_pos2} SPEED={travel_speed} SYNC=0 ACCEL={travel_acc}
    MANUAL_STEPPER STEPPER=motor_left MOVE={move_pos2} SPEED={travel_speed} SYNC=1 ACCEL={travel_acc}
  {% else %}
    MANUAL_STEPPER STEPPER=motor_right MOVE={move_pos1} SPEED={travel_speed} SYNC=1 ACCEL={travel_acc}
    MANUAL_STEPPER STEPPER=motor_right MOVE={move_pos2} SPEED={travel_speed} SYNC=1 ACCEL={travel_acc}
    MANUAL_STEPPER STEPPER=motor_right MOVE={move_pos1} SPEED={travel_speed} SYNC=1 ACCEL={travel_acc}
    MANUAL_STEPPER STEPPER=motor_right MOVE={move_pos2} SPEED={travel_speed} SYNC=1 ACCEL={travel_acc}
  {% endif %}
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

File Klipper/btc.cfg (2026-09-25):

[include ./btc_variables.cfg]  # Required

[input_shaper]                 # Required for input shaper, do not delete

[gcode_macro _UPDATE_FRONTEND]
gcode:
  # Macro object names and SET_GCODE_VARIABLE selectors are case sensitive.
  # Uppercase tool macros work in Mainsail and accept lowercase G-code commands in Fluidd.
  {% set tool_current_asperbtc = printer["gcode_macro _BTC_VARIABLES"].tool_current_asperbtc %}
  {% set numoftool = printer["gcode_macro _BTC_VARIABLES"].numoftool %}
  {% for toolnumber in numoftool %}
    {% set active = toolnumber == tool_current_asperbtc %}

    {% if "active" in printer["gcode_macro T" ~ toolnumber] %}
      { action_respond_info("Setting tool " ~ toolnumber ~ " active: " ~ active) }
      SET_GCODE_VARIABLE MACRO=T{toolnumber} VARIABLE=active VALUE={active}
      set_caselight_leds_on
    {% endif %}

    {% if printer["gcode_macro _BTC_VARIABLES"].btc_enable_spoolman_integration %}
      {% if active and "spool_id" in printer["gcode_macro T" ~ toolnumber] %}
        { action_respond_info("Tool " ~ toolnumber ~ " is active. Active spool is now " ~ printer["gcode_macro T" ~ toolnumber].spool_id) }
        SET_ACTIVE_SPOOL ID={ printer["gcode_macro T" ~ toolnumber].spool_id }
      {% endif %}
    {% endif %}
  {% endfor %}

  {% if printer["gcode_macro _BTC_VARIABLES"].btc_enable_spoolman_integration and tool_current_asperbtc == -1 %}
    { action_respond_info("No tool is active; clearing active spool") }
    CLEAR_ACTIVE_SPOOL
  {% endif %}

###################################################
# STARTUP ACTION PROMPTS
###################################################

[gcode_macro _PROMPT_STARTUP_TOOL]
description: Displays UI popup box in Mainsail to register mounted tool
gcode:
  RESPOND TYPE=command MSG="action:prompt_end"
  RESPOND TYPE=command MSG="action:prompt_begin BTC Startup: Tool Detected!"
  RESPOND TYPE=command MSG="action:prompt_text Select the tool currently mounted on the carriage:"
  RESPOND TYPE=command MSG="action:prompt_button_group_start"
  
  {% set numoftool = printer["gcode_macro _BTC_VARIABLES"].numoftool %}
  {% for toolnumber in numoftool %}
    RESPOND TYPE=command MSG="action:prompt_button T{toolnumber}|REGISTER_STARTUP_TOOL TOOL={toolnumber}|primary"
  {% endfor %}
  
  RESPOND TYPE=command MSG="action:prompt_button_group_end"
  RESPOND TYPE=command MSG="action:prompt_show"

[gcode_macro REGISTER_STARTUP_TOOL]
description: Registers selected tool from startup prompt
gcode:
  {% set toolnumber = params.TOOL|default(-1)|int %}
  RESPOND TYPE=command MSG="action:prompt_end"
  RECOVER_WITH_TOOL TOOL={toolnumber}
  _BTC_LED_SUCCESS
  
### start Printer start routine ###
[delayed_gcode start_check_carriage]
initial_duration: 3
gcode:
  {% for tools in range(6) %}
    {% if printer["gcode_macro T" + tools|string] is defined %}
      _START_POPULATE_TOOLS TOOLNUMBER={tools}
      { action_respond_info("BTC: Tool %d is defined" % (tools)) }
    {% endif %}
  {% endfor %}

  {% if printer["gcode_macro DOCKSLIDE_HOME"] is defined %}
    { action_respond_info("BTC: Dockslide is in use") }
    SET_GCODE_VARIABLE MACRO=_BTC_VARIABLES VARIABLE=use_dockslide VALUE=True
  {% else %}
    { action_respond_info("BTC: Dockslide is not in use") }
  {% endif %}
  
  {% set base_limit_accel = printer.toolhead.max_accel %}
  {% set base_limit_scv = printer.toolhead.square_corner_velocity %}
  SET_GCODE_VARIABLE MACRO=_BTC_VARIABLES VARIABLE=base_limit_accel VALUE={base_limit_accel}
  SET_GCODE_VARIABLE MACRO=_BTC_VARIABLES VARIABLE=base_limit_scv VALUE={base_limit_scv}

  UPDATE_DELAYED_GCODE ID=_start_check_second_delayed DURATION=2

[delayed_gcode _start_check_second_delayed]
initial_duration: 0
gcode:
  _STARTUP_CHECK_CARRIAGE_ACTION

[gcode_macro _STARTUP_CHECK_CARRIAGE_ACTION]
gcode:
  {% set carriage_pressed = printer["gcode_button carriage_sense"].state == "PRESSED" %}

  {% if carriage_pressed %}
    { action_respond_info("BTC: Tool detected on carriage at startup! Prompting user for registration.") }
    
    # Start blinking loop immediately
    UPDATE_DELAYED_GCODE ID=_BTC_LED_BLINK_LOOP DURATION=0.1
    
    _PROMPT_STARTUP_TOOL
    
    { action_respond_info("------------------------------------") }
    { action_respond_info("ACTION REQUIRED: Tool mounted on carriage.") }
    { action_respond_info("Run 'REGISTER_STARTUP_TOOL TOOL=N' (e.g. REGISTER_STARTUP_TOOL TOOL=0)") }
    { action_respond_info("------------------------------------") }
  {% else %}
    { action_respond_info("BTC: Carriage empty on startup. Proceeding normally.") }
    SET_GCODE_VARIABLE MACRO=_BTC_VARIABLES VARIABLE=tool_current_asperbtc VALUE=-1
    _UPDATE_FRONTEND
    
    # Set solid blue for empty carriage
    _BTC_LED_EMPTY
  {% endif %}

[gcode_macro _START_POPULATE_TOOLS]
gcode:
  {% set numoftool = printer["gcode_macro _BTC_VARIABLES"].numoftool + [params.TOOLNUMBER|int] %}
  SET_GCODE_VARIABLE MACRO=_BTC_VARIABLES VARIABLE=numoftool VALUE='{numoftool}'

### start Check state of carriage ###
[gcode_macro CHECK_CARRIAGE]
gcode:
  { action_respond_info("BTC: Check carriage start.") }
  {% set current_tool = printer["gcode_macro _BTC_VARIABLES"].tool_current_asperbtc %}
  {% set target_tool = params.TOOLNUMBER|default(current_tool)|int %}
  
  # If no active tool is set yet, default to target or 0
  {% if target_tool < 0 %}
    {% set target_tool = 0 %}
  {% endif %}

  {% set carriage_pressed = printer["gcode_button carriage_sense"].state == "PRESSED" %}

  {% if not carriage_pressed %}
    { action_respond_info("BTC: Carriage empty (sensor RELEASED)") }
    SET_GCODE_VARIABLE MACRO=_BTC_VARIABLES VARIABLE=tool_current_asperbtc VALUE=-1
    HOTSWAP_LED_EMPTY
  {% else %}
    { action_respond_info("BTC: Carriage engaged. Verifying T%d" % target_tool) }
    _CHECK_CARRIAGE_SECOND TOOLNUMBER={target_tool}
  {% endif %}
  _UPDATE_FRONTEND

[gcode_macro _CHECKASPERBTC]
gcode:
  {% if printer["gcode_macro _BTC_VARIABLES"].tool_current_asperbtc < 0 %}
    query_probe
    _CHECK_CARRIAGE_SECOND TOOLNUMBER={params.TOOLNUMBER|default(0)|int}
  {% endif %}
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

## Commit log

2026-08-26 Create Lineux Hotswap BOM Beta.xlsx
    [Lineux Hotswap BOM Beta.xlsx]
2026-08-28 First cad upload
2026-08-30 Cad upload
2026-08-30 Next cad and stl batch upload
    [5015_adapter.stl, 5015_standoff_x2.stl, [a]_5015_adapter.stl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]
2026-08-30 btc files upload
    [Lineux Hotswap BOM Alpha.xlsx, Lineux Hotswap BOM Beta.xlsx, bashed_macros.cfg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]
2026-08-30 Updated btc files
    [bashed_macros.cfg, btc_carriage.cfg, btc_nudge.cfg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]
2026-08-30 Updated btc
    [btc.cfg, btc_variables.cfg, tool_0.cfg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]
2026-09-01 Fix clearance issue on carriage
    [carriage.stl, carriage_front.stl]
2026-09-04 Fix 5015 adapter clearance to ab motor mount
    [5015_adapter.stl]
2026-09-10 Edited nozzle blocker
    Edited nozzle blocker to seat the silicon brush deeper for creality k1 brush.
    [[a]_nozzle_blocker.stl]
2026-09-10 edited dockslide mount
    edited dockslide mount to move further back to compensate for 2.4 max travel
2026-09-11 Optimized bashed macros
    [bashed_macros.cfg]
2026-09-11 Change macro names to be UPPERCASE to comply with Klipper guidelines
    [btc.cfg, btc_extras.cfg, btc_spoolman.cfg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]
2026-09-11 added 2 more tool smple
    [tool_0.cfg, tool_2.cfg, tool_3.cfg]
2026-09-12 Fix origin alignment
    Fix origin alignment for connector cover and logo for multi colour print
    [[a]_logo_connector_cover_molex.stl, connector_cover_molex6pin_arm.stl, connector_cover_molex6pin_noarm.stl]
2026-09-12 Update btc_extras.cfg
    Delete redundant macros.
    [btc_extras.cfg]
2026-09-12 Updated readme for klipper
2026-09-12 change m3x6mm set screw to m3x8mm
    change m3x6mm set screw to m3x8mm
    [Lineux Hotswap BOM Alpha.xlsx, Lineux Hotswap BOM Beta.xlsx]
2026-09-13 Updated dockslide
    Dockslide now has correct length for Hotswap
    [btc_extras.cfg]
2026-09-14 Added dockslide bom and stls
    Added dockslide bom and stls
    [Lineux Hotswap Dockslide 2.4 r2 350 Bom.xlsx, Lineux Hotswap Dockslide Vzbot 330 Bom.xlsx, [a]_belt_tensioner_x2.stl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]
2026-09-14 Uploaded Tubby and Intai bom cad and stl
    Uploaded Tubby and Intai bom cad and stl
    [Intai Bom.xlsx, Tubby Bom.xlsx, base_10x5.stl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]
2026-09-15 Edited duct extension and 5015 adapter
    Edited duct extension and 5015 adapter to accomodate trident r2 XY joint
    [5015_adapter.stl, duct_extension.stl]
2026-09-15 Added extra wall for 8x5 magnet in carriage
    Added extra wall for 8x5 magnet in carriage
    [btc.cfg, carriage.stl, carriage_front.stl]
2026-09-23 Edited dowel and magnet hole
    Edited dowel and magnet teardrop hole
    [dock.stl]
2026-09-25 Remove cutaway support
    Remove cutaway support for the ziptie slot for easier printing.
    Added helper scripts
    [dock_locate_calibrate.cfg]
2026-09-25 Updated tool stls
    [[a]_toolhead.stl, [a]_toolhead_12mm.stl]
2026-09-25 Updated btc
    Updated btc with tool retract moves
    [btc.cfg, btc_variables.cfg, tool_0.cfg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]
2026-10-01 Updated latch
    Updated latch for stiffness.
    Updated bom
    [Lineux Hotswap BOM Beta.xlsx, [a]_latch.stl, carriage.stl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]
2026-10-04 Added connector cover with ziptie
    Added connector cover with ziptie
2026-10-10 Fixed Belt slot to be symmetrical
    Fixed Belt slot to be symmetrical on carriage base for Voron Carriage
2026-10-11 Fixed revo voron shroud mount
    Fixed revo voron shroud mount to be symmetric
2026-10-11 Added wire channel to shroud mounts
    Added wire channel to shroud mounts
2026-10-17 Change filament path slot to hexagon
    Change filament path slot to hexagon
2026-10-17 Update bom to indicate 10t pinion
    Update bom to indicate 10t pinion for extruder stepper
2026-10-20 Updated Intai bom to indicate camera type
    Updated Intai bom to indicate camera type
2026-10-24 Fixed gear section spacing to be symmetrical
    Fixed gear section spacing to be symmetrical
2026-10-25 Updated panels size and bom for dockslide
    Updated panels size and bom for dockslide
2026-11-10 Improve aesthetic
    Improve aesthetic for gear plate and latch to align the centre hole.
    Moved heat insert for latch plate to be inserted from the back.
    Removed the need for support to carriage
2026-11-10 Fixed belt slots
    Fixed belt slots alignment
2026-11-11 Fixed grave issue with gear plate
    Fixed grave issue with gear plate.
    Vzbot affected part - Carriage, Gear plate
    Voron and cnc tap affected part - carriage, carriage base/carriage duct, gear plate
    Also take note of screw changes for voron and cnc tap
